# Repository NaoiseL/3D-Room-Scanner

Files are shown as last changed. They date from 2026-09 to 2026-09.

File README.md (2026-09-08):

# 3D Room Scanner

A 3D room scanner built from a 2D LiDAR, a stepper motor, and 3D-printed parts.
**190,000 points in 90 seconds.**

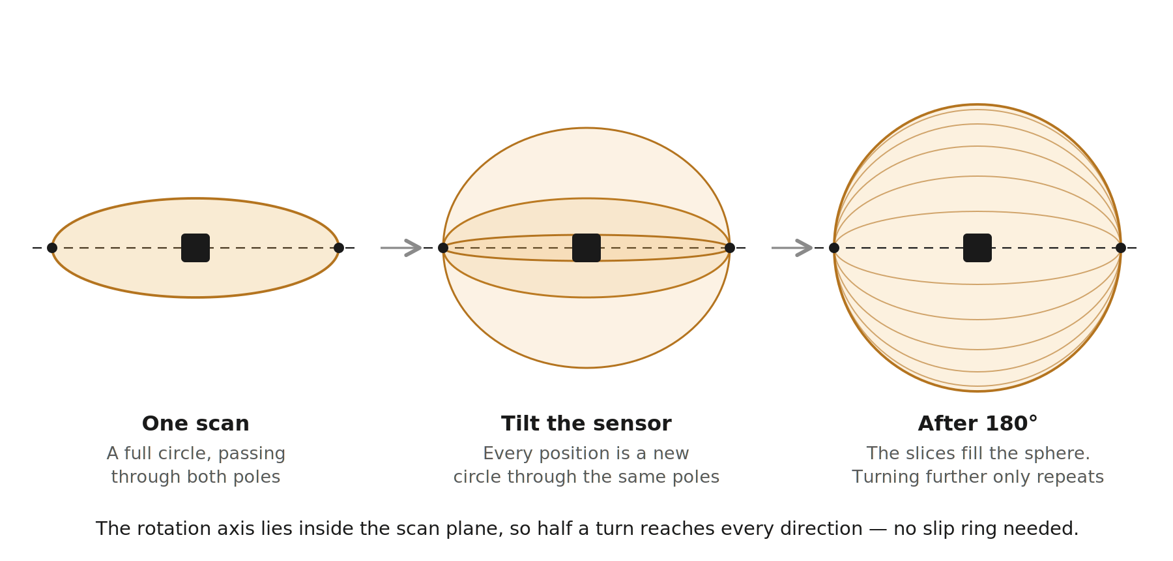
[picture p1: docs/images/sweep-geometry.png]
How a 180 degree sweep covers the whole sphere


The YDLIDAR X2L only measures a single horizontal slice. Mounted in a motorised tilting yoke
and swept through 180°, it becomes a full spherical scanner.

---

## The idea

A 2D LiDAR sweeps a plane. Reaching 3D needs a second axis — but the amount of rotation
required is less obvious than it looks.

Mount the sensor so that **the rotation axis lies inside the scan plane**. Each slice is then a
full circle through that axis, and rotating a plane 180° about an axis it contains sweeps it
through every possible orientation. One stop-to-stop pass covers the entire sphere. Going
further only re-scans what you already have.

That halves the travel a naive design would need, which means no slip ring and no
continuous-rotation wiring — just a service loop and two hard stops.

A point measured at in-plane bearing `θ` and range `d`, with the axis tilted by `β`:

```
x = d·cos θ
y = d·sin θ·cos β
z = d·sin θ·sin β
```

`θ` is measured **from the rotation axis**, so `θ = 0` is invariant under `β` — that ray never
moves as the axis tilts. That property is what the calibration exploits.

---

## Results

| | |
|---|---|
| Scan time | 91 s |
| Points per scan | 190,532 |
| Return rate | 79% |
| Corrupted packets | 0 of 242,270 rays |
| Sweep self-consistency | 6 mm, against 456 mm typical |
| Plane fit RMS | 9.5 mm over 28,386 points at 2.15 m |
| Angular step | 0.75° of tilt per full motor step |

The sweep self-consistency figure is worth explaining. A 180° sweep returns the scan plane to
where it started, mirrored, so the last slice must equal the first reflected about the pole.
Scoring that agreement measures the scanner's own angular error **without reference to the
scene**, and simultaneously proves the drive didn't lose steps.

---

## Quick start

No hardware needed — a real scan is included.

```bash
git clone https://github.com/NaoiseL/3D-Room-Scanner
cd 3D-Room-Scanner/software
pip install -r requirements.txt

python scan3d.py selftest                      # geometry checks
python x2l.py selftest                         # protocol decode, vs the datasheet's example

python scan3d.py verify  --raw ../data/sample_room.csv
python scan3d.py build   --raw ../data/sample_room.csv --offset 179 --mirror --out room.ply
python scan3d.py measure --raw ../data/sample_room.csv --offset 179
```

Open `room.ply` in [CloudCompare](https://cloudcompare.org) or MeshLab.

---

## Hardware

| Part | Notes | ~€ |
|---|---|---|
| YDLIDAR X2L | 0.12–8 m, 3000 Hz, 5–8 Hz scan, 0.84° resolution | 70 |
| NEMA 17 stepper | 1.8°/step | 12 |
| DRV8825 driver | 1/8 microstepping | 8 |
| Arduino Uno | Step generation and homing | 20 |
| 608 bearings ×2 | Tilt axis | 4 |
| 4S lithium pack + switch | Motor supply, 14.8 V nominal | 20 |
| USB power bank | Sensor supply, kept off the motor ground | — |
| Printed parts | Yoke, housings, gears, hard stops | 10 |

### Wiring

Go by the **printed labels** on the driver — some clone boards mirror the pin rows.

| DRV8825 | To |
|---|---|
| VMOT / GND | Battery pack, through the switch |
| A1, A2 / B1, B2 | Motor coil pairs |
| STEP / DIR / ENABLE | D3 / D4 / D5 |
| M0 / M1 / M2 | D8 / D9 / D10 |
| RESET + SLEEP | Arduino 5 V, tied together |
| GND (logic) | Arduino GND |

There is **no VDD pin** on the DRV8825 — it derives its logic supply from VMOT, so the driver
is completely dead without the motor supply. `RESET` and `SLEEP` are inputs and must be pulled
high or nothing responds.

Three power domains, one ground. Motor from the battery pack; Arduino from the host's USB;
sensor from a separate USB supply so motor return currents stay off its ground. Motor and logic
returns are run as separate wires meeting at the pack negative.

Three things that damage hardware: connecting the motor with the driver powered, omitting the
100 µF electrolytic across VMOT, and setting the current limit with the motor attached. Set
VREF to 0.25 V for a 0.5 A limit — far below the motor's rating, and ample for a balanced 125 g
load.

---

## Build

Gears are 20T/48T at module 1.25, 20° pressure angle, 2.4:1 — chosen so **one full motor step
is 0.75° of tilt**. That matters: the DRV8825's intermediate microsteps are not evenly spaced,
so the reduction is sized to keep every commanded position on a real full-step detent and take
microstep accuracy out of the error budget entirely.

* Print gears flat on the bed, teeth up, 4 perimeters, no supports. Never on edge — printed
  layers peel apart under tooth load.
* 0.12 mm backlash allowance. Zero-clearance printed gears bind.
* **Slot the motor mounting holes.** No printer hits a 42.5 mm centre distance first time.
* Ream the bores after printing. A 5 mm printed hole comes out around 4.8 mm.
* **Get the assembly close to balanced about the tilt axis.** An off-centre mass applies a
  moment that reverses sign through neutral, which can drive the gear teeth against alternate
  flanks mid-sweep. This build is only roughly balanced — unpowered it holds near neutral but
  falls away at steep angles, and in use it relies on the stepper's holding torque. That proved
  sufficient, but don't assume it: the `verify` residual measures any flank crossing directly.
* Two hard stops, 180° apart. No endstop switch is needed — see homing below.
* Keep the plane where the scan cuts the drive gear clear of everything. The gear rotates with
  the sensor, so anything on that line blocks the beam permanently.

STLs in [`cad/stl/`](cad/stl).

---

## Usage

Upload [`firmware/tilt_axis/tilt_axis.ino`](firmware/tilt_axis), then in the Serial Monitor at
115200 with Newline line endings:

| Command | Action |
|---|---|
| `?` | Status: position, degrees, endstop, direction |
| `C` | Crash home against the hard stop |
| `F<n>` | Step `n` full steps |
| `D1` / `D0` | Direction |
| `Z` | Zero here, manual datum |
| `T` | Self test |

Send `C`, **close the Serial Monitor**, then:

```bash
python scan3d.py scan      --lidar COM4 --arduino COM5 --out room.csv
python scan3d.py verify    --raw room.csv
python scan3d.py calibrate --raw room.csv --offset <from verify>
python scan3d.py build     --raw room.csv --offset <n> --oz <n> --gamma <n> --mirror --out room.ply
python scan3d.py measure   --raw room.csv --offset <n> --oz <n> --gamma <n>
```

Capture and reconstruction are deliberately separate. Scanning writes raw `(β, θ, range)` to
CSV; everything after is an instant second pass. Never re-scan to change a parameter.

### Reading the output

* **`scan` return rate below 60%** — the room exceeds the sensor's 8 m range, or the scanner is
  against a wall. Move toward the middle or pick a smaller space.
* **`verify` disagreement above ~300 mm at every candidate** — the drive lost steps, or
  something in the scene moved. That scan is not recoverable; rescan.
* **`build` extents** — one of the three should be your ceiling height. If none is, the offset
  is wrong.
* **Room comes out mirrored** — add `--mirror`. YDLIDAR bearings increase clockwise, which
  combined with the drive direction makes the reconstruction left-handed. This is a fixed
  property of a given build; determine it once against an asymmetric feature, then leave it set.
* **`measure` finding planes 0.3 m apart** — those are furniture, not walls. Calibrate on a
  clean scene; a cluttered room supplies cabinet doors and appliances as "planes" and the solve
  gets pulled in inconsistent directions.

---

## Homing without a sensor

The DRV8825 is a constant-current chopper: it regulates coil current regardless of load, so a
stall produces **no measurable electrical signature**. Sensorless homing of the kind a TMC2209
offers is not available.

Instead the axis drives deliberately into a printed hard stop and skips teeth. Crude, but
repeatable across trials — and repeatability is the only property that matters, since a
consistent offset is absorbed by the extrinsic calibration. `C` overshoots by 8 full steps so
it reaches the stop from anywhere in the travel, then eases off so the gears aren't left loaded.

---

## Calibration

Three things must be recovered before the cloud means anything.

**Axis bearing** — which in-plane bearing points along the rotation axis. Recovered by the
mirror-consistency test described under Results, which is independent of the scene. An earlier
method based on range invariance at the pole was abandoned after it confidently locked onto a
yoke arm occluding the beam: a fixed obstruction holds constant range across the sweep exactly
as a true pole does, and the two are indistinguishable to that test.

**Extrinsics** — the sensor's optical centre does not sit on the rotation axis, and the scan
plane isn't perfectly aligned to it. Both are solved by maximising the mutual squareness of the
extracted surfaces, since real walls, floors and ceilings are perpendicular. The lever arm
rotates *with* the sensor, so it is applied before the tilt rotation, not after.

**Handedness** — one flag, fixed per build, as above.

---

## Angle correction

The X2L datasheet specifies a per-point correction for the triangulation geometry:

```
correction = atan(21.8·(155.3 − D) / (155.3·D))     degrees
```

Omitting it bows flat walls subtly enough to be mistaken for a mechanical fault. `x2l.py`
implements the protocol directly from the development manual rather than the vendor SDK, and
`--no-correction` disables the term so the systematic error it removes can be plotted and
measured rather than taken on faith.

---

## Limitations

* 8 m maximum range confines this to rooms, not large spaces.
* Step-and-settle capture assumes a static scene for the full 90 seconds.
* Range bias is not characterised across distance; only relative precision is quantified.
* The solid drive gear removes about 3.4% of the sphere at one pole. A spoked ring gear would
  recover most of it.

## Planned

* Continuous-sweep capture with timestamp interpolation and point deskewing, benchmarked
  against step-and-settle as ground truth.
* Multi-position scans registered with ICP to fill occlusions.
* Camera–LiDAR fusion to colourise the cloud, adding a second extrinsic calibration.

---

## Repository layout

```
firmware/tilt_axis/    Arduino stepper control, homing, serial command set
software/x2l.py        YDLIDAR X2L driver, protocol implemented from the datasheet
software/scan3d.py     capture, calibration, reconstruction, measurement
cad/stl/               printable parts
data/                  a real scan, so the pipeline runs with no hardware
docs/images/           figures
```

## Licence

MIT

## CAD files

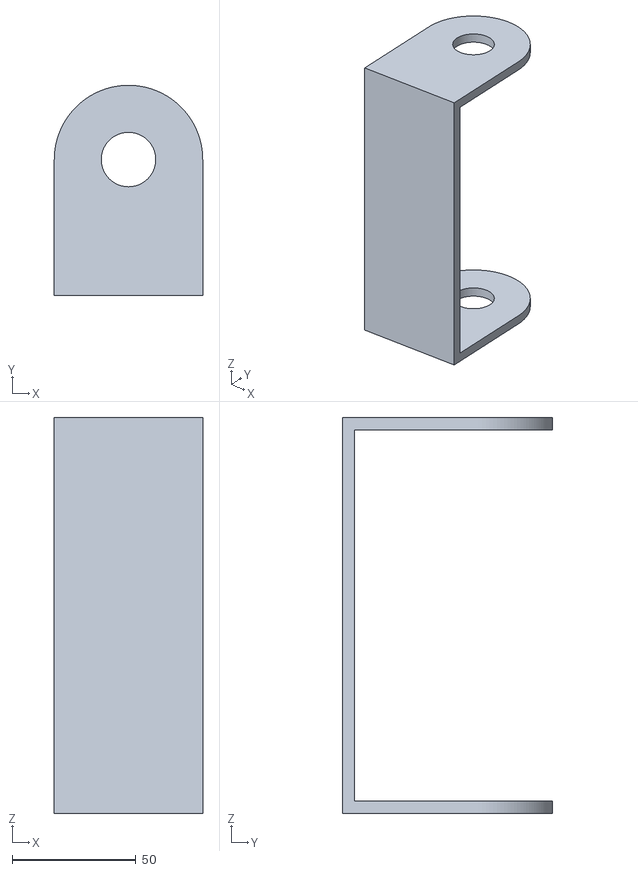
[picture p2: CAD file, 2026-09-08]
cad/stl/main_housing.stl
60.0 x 85.0 x 160.0

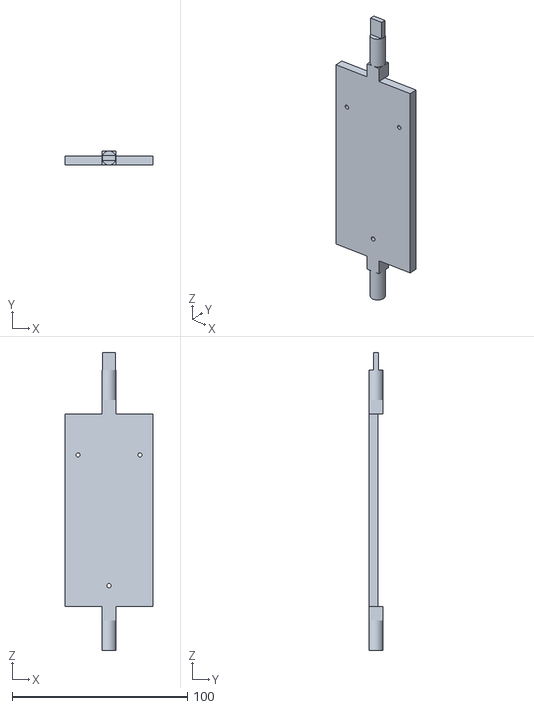
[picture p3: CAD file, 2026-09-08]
cad/stl/swivel_yoke.stl
50.0 x 8.00 x 170.0

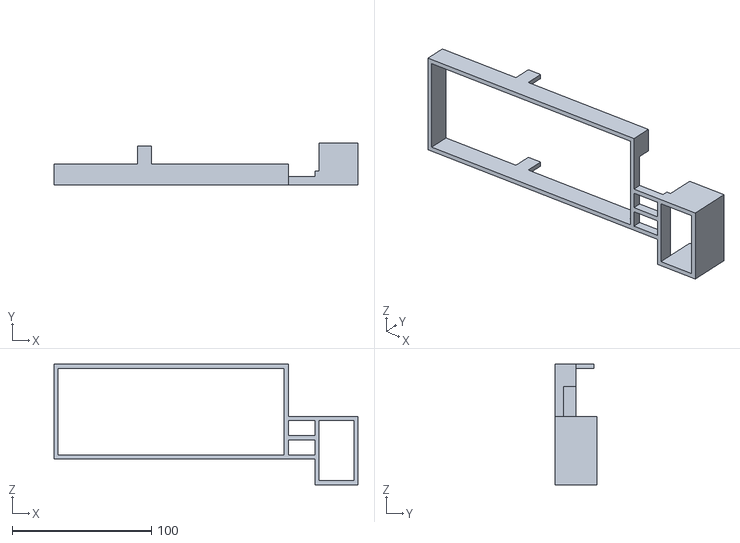
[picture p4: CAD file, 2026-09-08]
cad/stl/outer_housing.stl
218.0 x 30.0 x 86.5

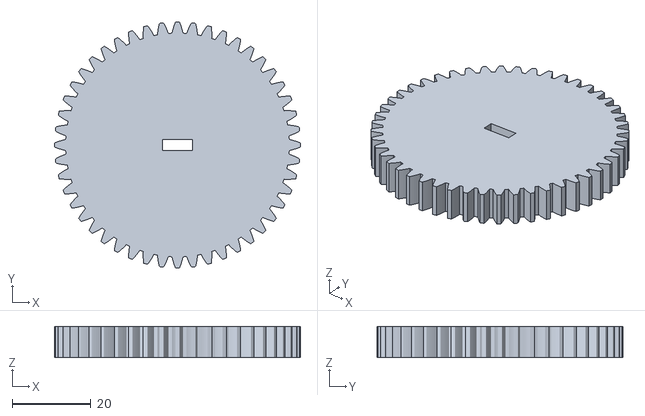
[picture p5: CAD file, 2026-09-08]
cad/stl/gear_48t_module1-25.stl
62.5 x 62.5 x 8.00

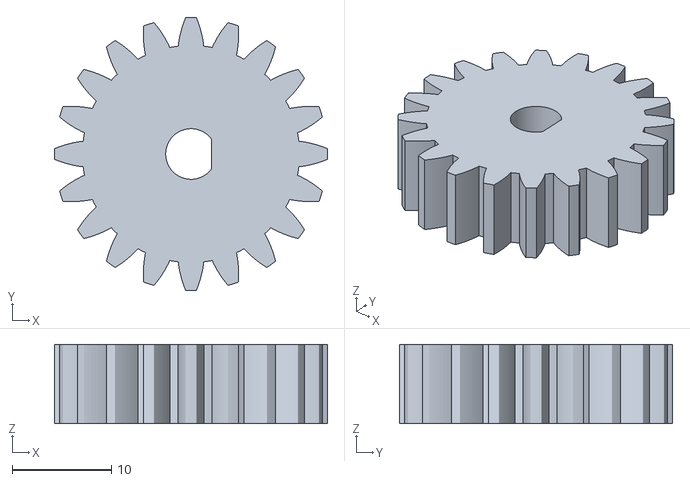
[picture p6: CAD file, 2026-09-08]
cad/stl/pinion_20t_module1-25.stl
27.5 x 27.5 x 8.00

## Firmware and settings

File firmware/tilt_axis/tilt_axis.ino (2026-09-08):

/*
  Tilt axis test firmware - DRV8825 + NEMA 17 + Arduino Uno

  Gearing: 20T pinion / 48T gear = 2.4:1
  Motor:   1.8 deg/step, 200 full steps/rev
  Driver:  1/8 microstepping

  One full step  = 1.8 / 2.4          = 0.75 deg of tilt
  One microstep  = 0.75 / 8           = 0.09375 deg
  Full sweep     = 180 deg            = 1920 microsteps

  Always stop on a multiple of 8 microsteps so the axis lands on a
  real full-step detent. The DRV8825's intermediate microsteps are
  not evenly spaced, so positions between detents are not trustworthy.

  Serial commands at 115200:
    ?        status
    E1 / E0  enable / disable driver
    D1 / D0  direction
    S<n>     step n microsteps in the current direction
    F<n>     step n FULL steps (n*8 microsteps) - prefer this
    H        home against an endstop switch
    C        crash home against the mechanical hard stop
    Z        zero here, manual datum for when no endstop is fitted
    T        self test: quarter turn out and back
*/

const uint8_t PIN_STEP    = 3;
const uint8_t PIN_DIR     = 4;
const uint8_t PIN_ENABLE  = 5;   // active LOW
const uint8_t PIN_M0      = 8;
const uint8_t PIN_M1      = 9;
const uint8_t PIN_M2      = 10;
const uint8_t PIN_ENDSTOP = 2;   // to GND, uses internal pullup

const uint8_t  MICROSTEPS      = 8;
const int      PULSE_US        = 3;      // DRV8825 needs >1.9us
const unsigned STEP_INTERVAL   = 600;    // us between microsteps
const unsigned HOME_INTERVAL   = 1500;   // slower approach when homing
const long     MICROSTEPS_180  = 1920;

long position = 0;          // microsteps from home
bool homed    = false;
bool dirFwd   = true;

void setMicrostepping() {
  // DRV8825: 1/8 step is M0 HIGH, M1 HIGH, M2 LOW
  digitalWrite(PIN_M0, HIGH);
  digitalWrite(PIN_M1, HIGH);
  digitalWrite(PIN_M2, LOW);
}

void enableDriver(bool on) {
  digitalWrite(PIN_ENABLE, on ? LOW : HIGH);
}

bool endstopHit() {
  return digitalRead(PIN_ENDSTOP) == LOW;
}

void setDirection(bool forward) {
  dirFwd = forward;
  digitalWrite(PIN_DIR, forward ? HIGH : LOW);
  delayMicroseconds(5);      // DIR setup time before the next STEP edge
}

void oneStep(unsigned intervalUs) {
  digitalWrite(PIN_STEP, HIGH);
  delayMicroseconds(PULSE_US);
  digitalWrite(PIN_STEP, LOW);
  delayMicroseconds(intervalUs);
  position += dirFwd ? 1 : -1;
}

void move(long microsteps) {
  setDirection(microsteps >= 0);
  long n = microsteps < 0 ? -microsteps : microsteps;
  for (long i = 0; i < n; i++) {
    if (!dirFwd && endstopHit()) {
      Serial.println(F("stopped: endstop"));
      return;
    }
    oneStep(STEP_INTERVAL);
  }
}

bool home() {
  Serial.println(F("homing..."));
  setDirection(false);

  // Back off first in case we are already sitting on the switch.
  if (endstopHit()) {
    setDirection(true);
    for (int i = 0; i < 40 * MICROSTEPS; i++) oneStep(HOME_INTERVAL);
    setDirection(false);
  }

  long guard = MICROSTEPS_180 * 2;
  while (!endstopHit() && guard-- > 0) oneStep(HOME_INTERVAL);

  if (guard <= 0) {
    Serial.println(F("FAILED: no endstop found"));
    homed = false;
    return false;
  }

  // Back off and approach again slowly for a repeatable datum.
  setDirection(true);
  for (int i = 0; i < 16 * MICROSTEPS; i++) oneStep(HOME_INTERVAL);
  setDirection(false);
  while (!endstopHit()) oneStep(HOME_INTERVAL * 3);

  position = 0;
  homed = true;
  Serial.println(F("homed"));
  return true;
}

bool crashHome() {
  // Homing with no switch: drive into the mechanical hard stop and let the
  // motor skip steps. The DRV8825 holds current constant regardless of load,
  // so a stall is not detectable electrically. We simply command more travel
  // than the axis has and trust the stop to absorb it.
  //
  // Repeatable to roughly one full step. Good enough for bring-up, and a
  // constant offset gets absorbed by extrinsic calibration later, but a
  // contact switch is meaningfully better.
  Serial.println(F("crash homing..."));
  setDirection(false);

  const long overtravel = MICROSTEPS_180 + 8L * MICROSTEPS;
  for (long i = 0; i < overtravel; i++) oneStep(HOME_INTERVAL);

  // Ease off so the gears are not left loaded against the stop.
  setDirection(true);
  for (int i = 0; i < 2 * MICROSTEPS; i++) oneStep(HOME_INTERVAL);

  position = 0;
  homed = true;
  Serial.println(F("at hard stop, zeroed"));
  return true;
}

void status() {
  Serial.print(F("pos "));       Serial.print(position);
  Serial.print(F("  deg "));     Serial.print(position * 0.09375, 3);
  Serial.print(F("  homed "));   Serial.print(homed ? 'y' : 'n');
  Serial.print(F("  endstop ")); Serial.print(endstopHit() ? "HIT" : "open");
  Serial.print(F("  dir "));     Serial.println(dirFwd ? '+' : '-');
}

void setup() {
  pinMode(PIN_STEP,   OUTPUT);
  pinMode(PIN_DIR,    OUTPUT);
  pinMode(PIN_ENABLE, OUTPUT);
  pinMode(PIN_M0,     OUTPUT);
  pinMode(PIN_M1,     OUTPUT);
  pinMode(PIN_M2,     OUTPUT);
  pinMode(PIN_ENDSTOP, INPUT_PULLUP);

  enableDriver(false);
  setMicrostepping();
  setDirection(true);

  Serial.begin(115200);
  while (!Serial) { }
  Serial.println(F("tilt axis ready. commands: ? E1 E0 D1 D0 S<n> F<n> H C Z T"));
  enableDriver(true);
}

void loop() {
  if (!Serial.available()) return;

  char c = Serial.read();
  switch (c) {
    case '?': status(); break;

    case 'E': {
      char v = Serial.read();
      enableDriver(v == '1');
      Serial.println(v == '1' ? F("enabled") : F("disabled"));
      break;
    }

    case 'D': {
      char v = Serial.read();
      setDirection(v == '1');
      Serial.println(dirFwd ? F("dir +") : F("dir -"));
      break;
    }

    case 'S': {
      long n = Serial.parseInt();
      move(dirFwd ? n : -n);
      status();
      break;
    }

    case 'F': {
      long n = Serial.parseInt();
      move((dirFwd ? n : -n) * MICROSTEPS);
      status();
      break;
    }

    case 'H': home(); status(); break;

    case 'C': crashHome(); status(); break;

    case 'Z':
      // Manual datum. Park the axis where you want zero by eye, then send Z.
      // Use this until a real endstop exists; it is repeatable only as far
      // as your eye is, so it is for bring-up, not for real scans.
      position = 0;
      homed = true;
      Serial.println(F("zeroed here (manual datum)"));
      break;

    case 'T': {
      Serial.println(F("self test: 60 full steps out and back"));
      move(60L * MICROSTEPS);
      delay(400);
      move(-60L * MICROSTEPS);
      status();
      break;
    }

    default: break;   // ignore newlines and stray characters
  }
}

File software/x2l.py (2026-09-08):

"""
Minimal YDLIDAR X2L driver: raw serial -> (angle_deg, distance_mm) points.

Protocol per the YDLIDAR X2 Development Manual v1.2.
The lidar starts ranging automatically on power-up; no start command is sent.

Usage:
    python x2l.py --port COM4 plot
    python x2l.py --port /dev/ttyUSB0 ruler --bearing 0 --n 30
    python x2l.py selftest
"""

import argparse
import math
import statistics
import struct
import sys

# The packet header is the 16-bit value 0x55AA sent low byte first,
# so on the wire it is AA then 55.
HEADER = b"\xaa\x55"

# Constants from the second-level angle correction formula in the manual.
_K1 = 21.8
_K2 = 155.3


def angle_correction_deg(distance_mm):
    """Second-level angle correction. Zero for invalid (zero) returns."""
    if distance_mm <= 0:
        return 0.0
    return math.degrees(
        math.atan(_K1 * (_K2 - distance_mm) / (_K2 * distance_mm))
    )


def parse_packet(pkt, correct=True):
    """
    Parse one scan packet.

    Returns (is_lap_start, [(angle_deg, distance_mm), ...]) or None if the
    checksum fails.

    Layout:  PH(2) CT(1) LSN(1) FSA(2) LSA(2) CS(2) S1(2) ... SN(2)
    """
    ph, ct_lsn, fsa, lsa, cs = struct.unpack("<HHHHH", pkt[:10])
    lsn = (ct_lsn >> 8) & 0xFF
    ct = ct_lsn & 0xFF

    samples = struct.unpack("<%dH" % lsn, pkt[10:10 + 2 * lsn])

    # Checksum is the XOR of every 16-bit word in the packet except CS itself.
    chk = ph ^ ct_lsn ^ fsa ^ lsa
    for s in samples:
        chk ^= s
    if chk != cs:
        return None

    # First-level analysis: bit 0 of each angle field is a parity bit.
    a_start = (fsa >> 1) / 64.0
    a_end = (lsa >> 1) / 64.0
    span = a_end - a_start
    if span < 0:
        span += 360.0

    points = []
    for i, s in enumerate(samples):
        distance = s / 4.0
        angle = a_start + (span * i / (lsn - 1) if lsn > 1 else 0.0)
        if correct:
            angle += angle_correction_deg(distance)
        points.append((angle % 360.0, distance))

    # CT bit 0 marks the first packet of a new revolution.
    return bool(ct & 1), points


class X2L:
    def __init__(self, port, baud=115200, timeout=1.0, correct=True):
        import serial
        self.ser = serial.Serial(port, baud, timeout=timeout)
        self.buf = bytearray()
        self.correct = correct
        self.stats = {"ok": 0, "bad_checksum": 0}

    def close(self):
        self.ser.close()

    def __enter__(self):
        return self

    def __exit__(self, *_):
        self.close()

    def packets(self):
        """Yield (is_lap_start, points) for every valid packet."""
        while True:
            waiting = self.ser.in_waiting
            chunk = self.ser.read(waiting if waiting else 1)
            if chunk:
                self.buf.extend(chunk)

            while True:
                i = self.buf.find(HEADER)
                if i < 0:
                    # Keep one byte in case a header straddles the boundary.
                    del self.buf[:-1]
                    break
                if len(self.buf) < i + 10:
                    del self.buf[:i]
                    break
                lsn = self.buf[i + 3]
                length = 10 + 2 * lsn
                if len(self.buf) < i + length:
                    del self.buf[:i]
                    break

                pkt = bytes(self.buf[i:i + length])
                del self.buf[:i + length]

                result = parse_packet(pkt, self.correct)
                if result is None:
                    self.stats["bad_checksum"] += 1
                else:
                    self.stats["ok"] += 1
                    yield result

    def scans(self, skip_first=True):
        """Yield one complete revolution at a time as a list of points."""
        current = []
        started = not skip_first
        for is_start, points in self.packets():
            if is_start:
                if current and started:
                    yield current
                started = True
                current = []
            if started:
                current.extend(points)


def shift(angle_deg, offset_deg):
    """Re-reference a raw bearing so the physical front of the unit reads 0."""
    return (angle_deg - offset_deg) % 360.0


def to_xy(angle_deg, distance_mm):
    """Bearing measured clockwise from straight ahead -> (x right, y forward), metres."""
    r = math.radians(angle_deg)
    d = distance_mm / 1000.0
    return d * math.sin(r), d * math.cos(r)


def cmd_xy(args):
    """Cartesian view. Flat walls should look flat here; in polar they never do."""
    import matplotlib.pyplot as plt
    import numpy as np

    limit = args.range
    with X2L(args.port, correct=not args.no_correction) as lidar:
        fig, ax = plt.subplots(figsize=(7, 7))
        ax.set_aspect("equal")
        ax.set_xlim(-limit, limit)
        ax.set_ylim(-limit, limit)
        ax.set_xlabel("x, metres")
        ax.set_ylabel("y, metres (0 deg is straight ahead)")
        ax.grid(True, alpha=0.3)
        ax.axhline(0, lw=0.5, color="0.7")
        ax.axvline(0, lw=0.5, color="0.7")
        scatter = ax.scatter([], [], s=3)
        plt.ion()
        plt.show()

        for scan in lidar.scans():
            pts = [
                to_xy(shift(a, args.offset), d)
                for a, d in scan
                if 120.0 < d <= 8000.0
            ]
            if not pts:
                continue
            scatter.set_offsets(np.asarray(pts))
            ax.set_title("%d points   bad checksums: %d"
                         % (len(pts), lidar.stats["bad_checksum"]))
            plt.pause(0.001)
            if not plt.fignum_exists(fig.number):
                break


def _fit_window(P):
    """Total-least-squares line fit. Returns (rms_mm, extent_m)."""
    import numpy as np
    centroid = P.mean(axis=0)
    _, _, vt = np.linalg.svd(P - centroid, full_matrices=False)
    resid = (P - centroid) @ vt[1] * 1000.0
    extent = float(np.ptp((P - centroid) @ vt[0]))
    return float(np.sqrt((resid ** 2).mean())), extent
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

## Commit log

2026-09-08 Reorganise into folders, normalise filenames
    [gear_48t_module1-25.stl, main_housing.stl, outer_housing.stl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]
2026-09-08 Add firmware, sample scan, figures, project docs
    [sample_room.csv]
